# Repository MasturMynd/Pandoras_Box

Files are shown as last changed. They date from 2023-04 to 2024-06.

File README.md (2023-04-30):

# Pandoras_Box

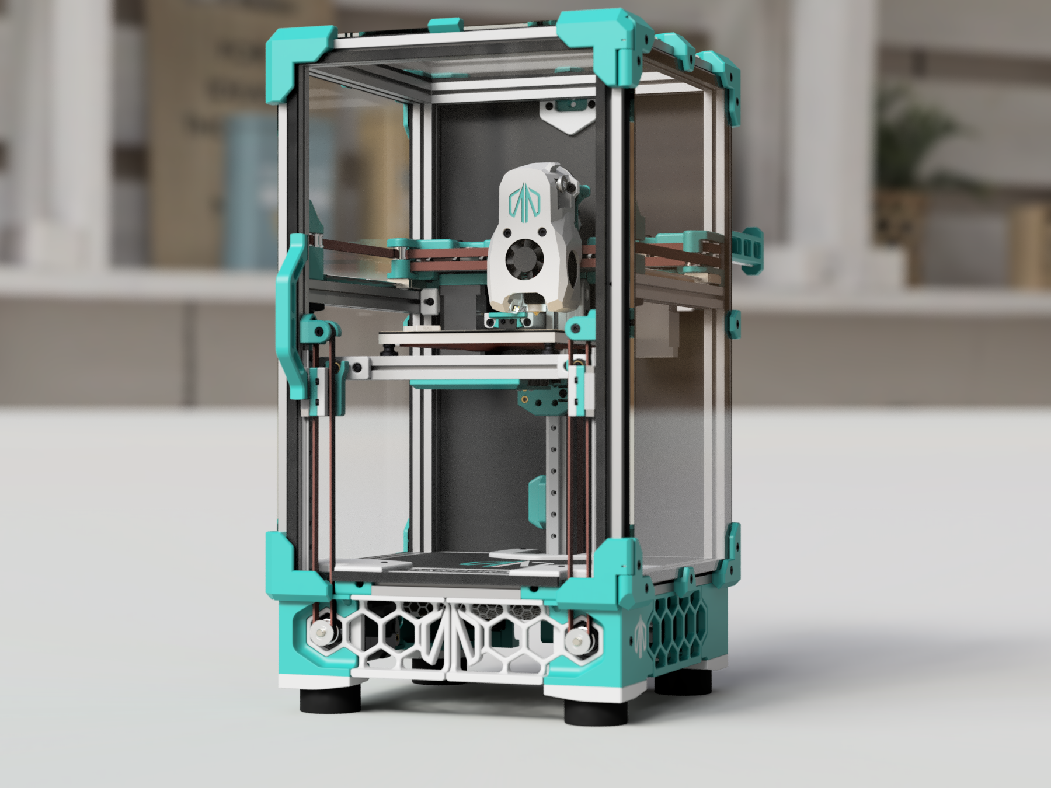
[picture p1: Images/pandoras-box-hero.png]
Pandoras_box_full


Pandora's Box is a modified version of the popular Voron V0 3D printer design. The printer has been enhanced with additional X and Y travel, a triple belted Z kinematic system, and an automatic bed tramming and meshing system.

## Features

- Increased X and Y travel - More room for activities!
- Triple belted Z kinematic system for stability and precision during Z-axis movement
- Automatic bed tramming and meshing system for effortless leveling of the print bed
- High-quality prints with improved accuracy and consistency
- Sturdy construction and triple belted Z kinematic system prevent any wobbling or shaking during printing

BOM
---
| Category | Part Description | Qty | Notes |
| --- | --- | --- | --- |
| Filament | Estimates based on the initial release | | |
| | Primary Color | 600g | |
| | Accent Color | 200g | |
| Fasteners | Listed quantities are minimum, buy extra! | | |
| | M2x6 FHCS | 9 | |
| | M2x6 SHCS | 62 | |
| | M2 Nut | 50 | |
| | M2x10 Self Tapping Screws for Plastic | 9 | |
| | M3x6 BHCS | 46 | |
| | M3x8 BHCS | 48 | |
| | M3x10 BHCS | 16 | |
| | M3x12 BHCS | 15 | |
| | M3x16 BHCS | 13 | |
| | M3x25 BHCS | 5 | |
| | M3x30 BHCS | 10 | |
| | M3x35 BHCS | 4 | |
| | M3x40 BHCS | 4 | |
| | M3x8 SHCS | 36 | |
| | M3x10 SHCS | 51 | |
| | M3x12 SHCS | 5 | |
| | M3x14 SHCS | 3 | Used only with Formbot build plates |
| | M3x16 SHCS | 7 | |
| | M3x20 SHCS | 4 | |
| | M3x25 SHCS | 6 | |
| | M3x30 SHCS | 4 | |
| | M3x35 SHCS | 2 | |
| | 3x6x0.5 Shim Washer | 42 | |
| | M3 Nut | 148 | |
| | M3 Brass heatstake inserts - short M3x5x4 | 62 | |
| | M5x16 BHCS | 4 | |
| | M5 Nut | 4 | |
| Frame | | | Full frame kit available at [DLLPDF](https://dllpdf.com/pandoras-box-frame)! |
| | Makerbeam XL 15x15 350mm | 4 | |
| | Makerbeam XL 15x15 200mm | 13 | |
| | Makerbeam XL 15x15 100mm | 3 | |
| Electronics | | |
| | Raspberry Pi Compute Module 4 | 1 | Alternative: Bigtreetech CB1 |
| | Omron Mouse Button - Micro Switch | 2 | |
| | NEMA17 Stepper Motor 45Ncm | 3 | Z Steppers - NEMA14 mounting also available |
| | NEMA14 Stepper Motor 40Ncm | 2 | |
| | MicroSD Card | 1 | |
| | Meanwell LRS-150-24 | 1 | UHP-200-24 is a stronger alternative |
| | IEC320 C14 inlet | 1 | |
| | Hotend thermistor | 1 | |
| | Hotend | 1 | |
| | C13 Power Cord | 1 | |
| | Bigtreetech Manta M8P | 1 | Alternative: Bigtreetech Manta M5P + CAN Toolhead Board |
| | 3M 5952 VHB tape | 1 | |
| | 3010 Blower Fan | 2 | |
| | 3010 Axial fan | 1 | |
| | 4010 Axial fan | 2 | |
| | 24V Heater Cartridge | 1 | |
| Cables | | |
| | Wire 18gauge 10ft | 1 | |
| | Thermal Fuse 125C | 1 | |
| | Nylon Cable Ties (1.8mm wide or smaller) | 50 | |
| | Microfit3 Dual Row (10circuits) Male & Female Plug | 1 | |
| | JST connectors (2pin 3pin 4pin) | ? | |
| | Insulated Crimp Receptical | 4 | |
| | High Flex Wire 22gauge 100ft | 1 | |
| | High Flex Wire 20gauge 10ft | 1 | |
| | 7mm x 7mm cable chain (less than 1/2 meter needed) | 1 | |
| | WAGO 221-412 (OPTIONAL) | 7 | |
| Motion | | |
| | MGN7H Linear Rail with Carriage - 150mm | 5 | |
| | MGN9H Linear Rail with Carriage - 200mm | 1 | |
| | GT2 Open Belt (6mm W) - 4000mm | 1 | |
| | GT2 20T (5mm ID 6mm W) | 5 | |
| | GT2 20T (5mm ID 6mm W) Deflanged | 1 | |
| | F623-RS Bearing | 42 | |
| | KGLM-03 Spherical Bearing	 | 3 | |
| | 5x25mm Shaft (Length varies by setup) | 1 | |
| Buildplate | | |
| | M4 Knurled Nut | 3 | |
| | Spring Steel Flex Buildplate 120x120mm (OPTIONAL) | 1 | |
| | Silicone DC 24V Heater 100x100mm 60W | 1 | |
| | PEI + 3M 468MP (200MP) | 1 | |
| | MIC6 1/4" Plate - 120x120mm | 1 | |
| Panels | | | Full panels kit available at [DLLPDF](https://dllpdf.com/pandoras-box-panels)! |
| | Rear Panel 3mm thick (See DXF) | 1 | |
| | Deck Panel 3mm thick (See DXF) | 1 | |
| | Acrylic Sheet Clear - 212x332x3mm | 3 | |
| | Acrylic Sheet Clear - 212x212x3mm | 1 | |
| | Single Sided Foam Tape 3mm Thick (5m) | 1 | |
| Bowden | | |
| | Bowden Tube 4x2mm - 1m | 1 | |
| | Bowden Fitting | 2 | |
| Misc. | | |
| | Rubber Foot (1.5x.75", 38x19mm) | 4 | |
| | Bowden Tube 4x3mm - 1m | 1 | |
| | 6mm x 3mm Round Neodymium Magnets | 18 | |
| Extruder | | |
| | NEMA14 36mm pancake Motor with 10 tooth gear | 1 | |
| | MR85 Bearing | 2 | |
| | Bondtech BMG Extruder Kit | 1 | |

## Usage

The Pandora's Box design can be used by hobbyists and professionals alike to produce high-quality 3D prints. The automatic bed tramming and meshing system saves time and effort while ensuring consistent and level prints.

## Contributing

If you would like to contribute to the Pandora's Box design or submit mods specific to this design, please feel free to fork the repository and submit a pull request with your changes. I welcome any and all contributions that help to improve the design and make it even more useful for the 3D printing community.

## License

The Pandora's Box 3D printer design is licensed under the GPLv3 License. Please see the `LICENSE` file for more information.

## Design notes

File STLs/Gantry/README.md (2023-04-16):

# Mini Stealthburner - MasturMods Edition

Mini Stealthburner - MasturMods Edition

There are two parts needed for this front cowling. First, print the insert out of your primary color. After you have that part ready slice the main body and insert a filament change or pause command at layer 16 (assuming traditional Voron print standards). When the print for the main body pauses, drop the insert into the formed gap in the part. This allows for a recessed logo with some flare!

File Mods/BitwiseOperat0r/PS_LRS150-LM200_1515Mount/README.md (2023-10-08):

Power supply mount for Meanwell LRS-150 or Mornsun LM200.

This is for standard Pandora's Box(NOT the +50)

I might want to go back and add some cable management to the mounts




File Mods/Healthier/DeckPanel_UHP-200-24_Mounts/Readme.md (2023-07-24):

# Deck Panel with UHP-200-24 mounts (Mastur_Mynd logo)

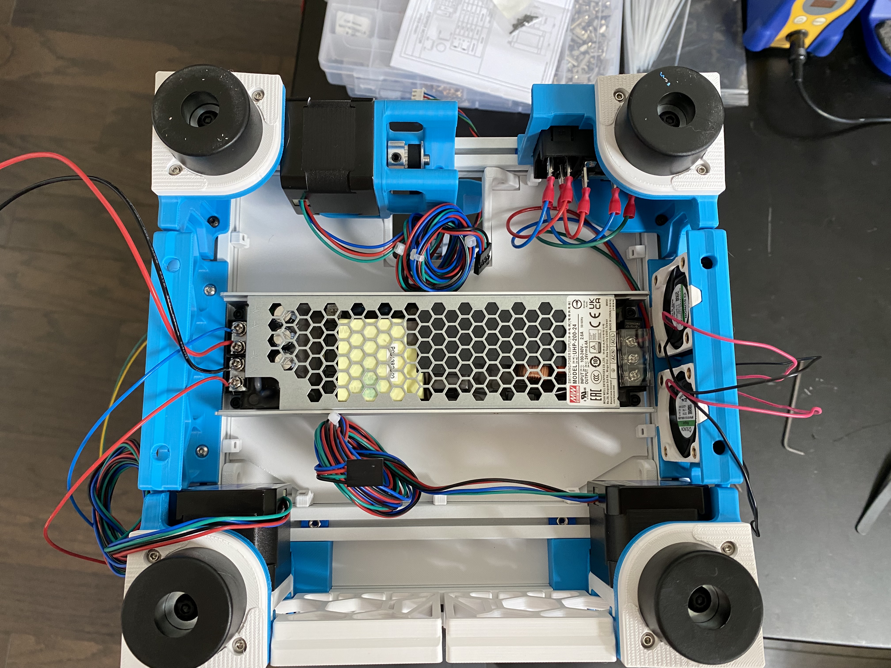
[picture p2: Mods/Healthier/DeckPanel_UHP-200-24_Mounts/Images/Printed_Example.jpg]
Printed_Example


A modified version of the Pandora Deck panel with raised spots for 3x4x5 heatset inserts in a pattern fitting a UHP-200-24

# Photos

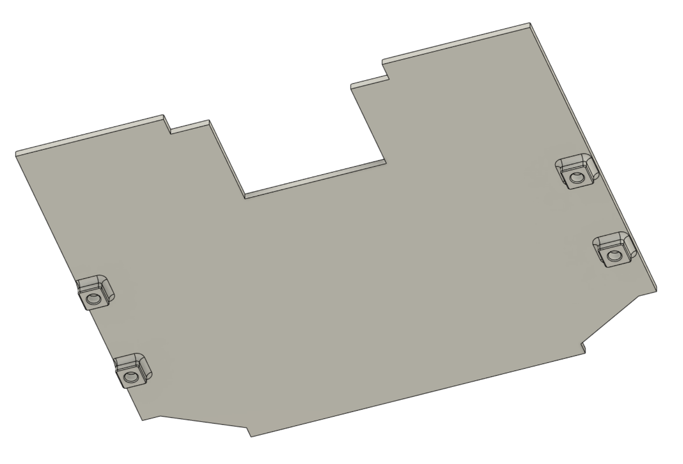
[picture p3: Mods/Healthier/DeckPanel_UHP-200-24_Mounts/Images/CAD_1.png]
CAD_1

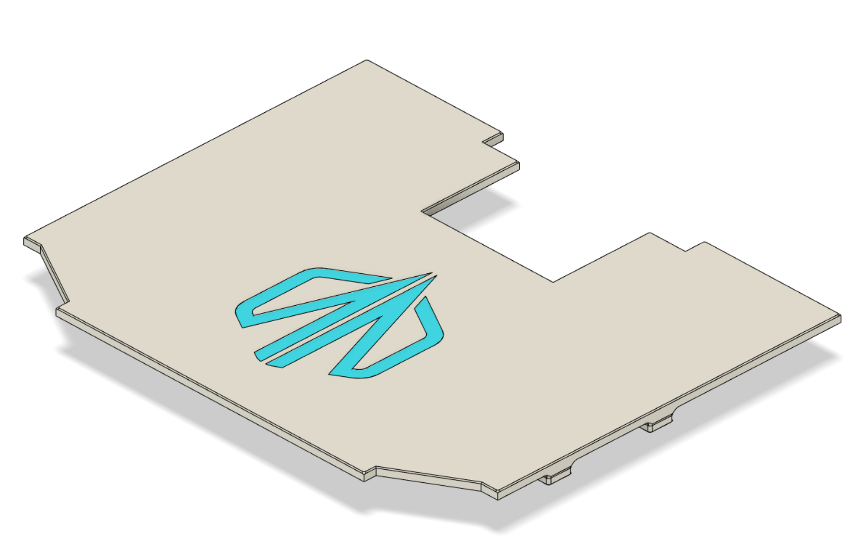
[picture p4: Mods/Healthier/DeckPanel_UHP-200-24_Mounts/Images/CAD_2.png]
CAD_2


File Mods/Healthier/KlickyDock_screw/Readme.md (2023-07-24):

# Klicky probe dock for Pandora - Screw option and better mounting support

A modified version of the Pandora Klicky probe mount / arm that supports a Black Oxide M3x8 SHCS screw in addition to the normal magnet.  This allows for variable strength of the magnet holding the probe in the dock.  In addition, the stabilizers around the mounting holes of the arms have been extended to the sides of the arm for better mounting stability.

# Photos

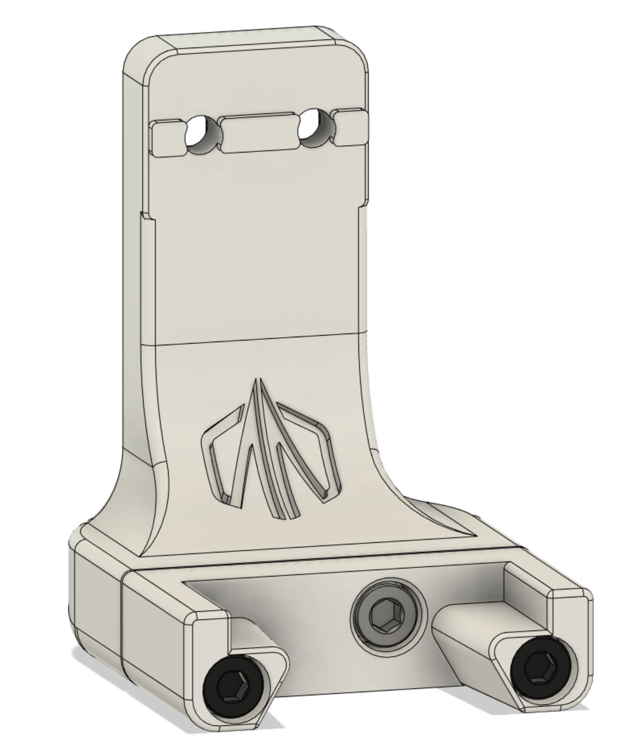
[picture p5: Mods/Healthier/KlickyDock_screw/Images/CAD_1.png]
CAD_1


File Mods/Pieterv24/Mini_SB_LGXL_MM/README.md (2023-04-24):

# Mini Stealthburner LGXL (Mastur_Mynd logo)

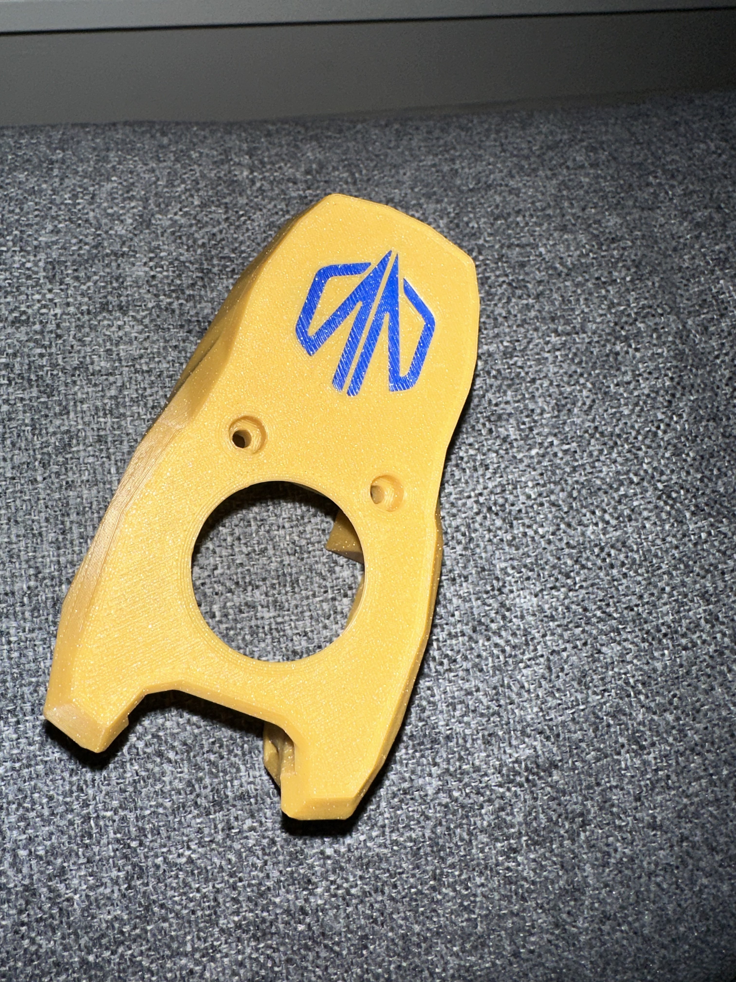
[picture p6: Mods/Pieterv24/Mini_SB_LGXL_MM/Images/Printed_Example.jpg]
Printed_Example


A modified version of the Mini Stealthburner LGLX cowling, with the Mastur_Mynd logo

[Original cowling](https://github.com/PrintersForAnts/Crucible/tree/main/MiniSB_LGXL)

# Photos

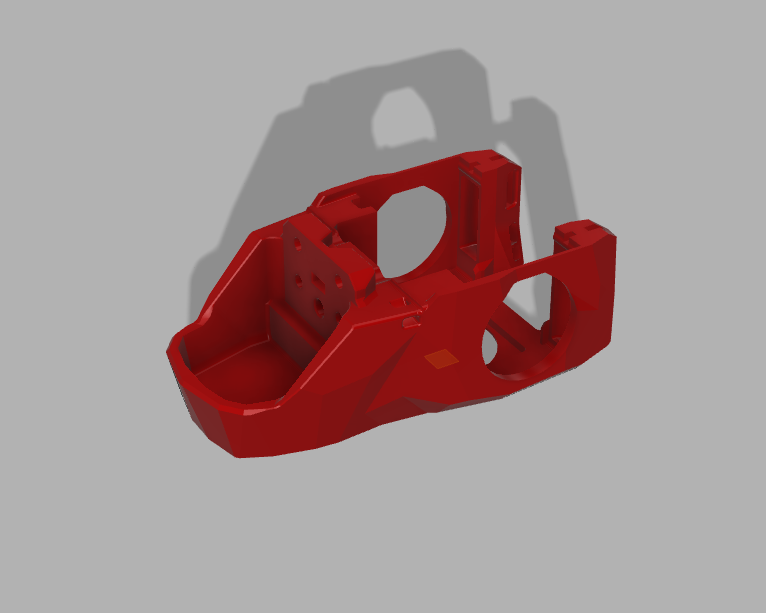
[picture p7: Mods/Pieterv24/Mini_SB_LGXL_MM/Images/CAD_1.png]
CAD_1

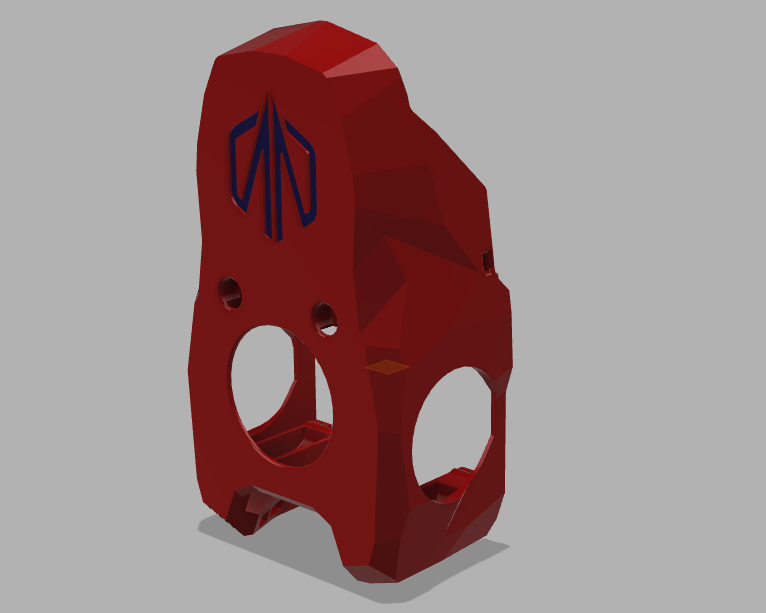
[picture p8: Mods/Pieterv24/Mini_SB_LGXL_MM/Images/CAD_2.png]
CAD_2

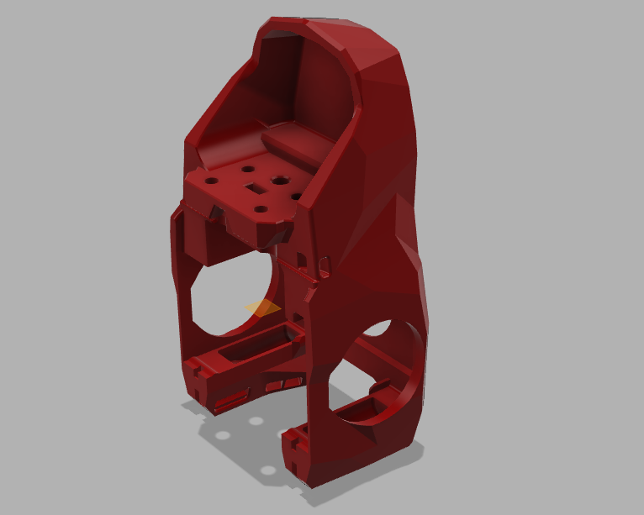
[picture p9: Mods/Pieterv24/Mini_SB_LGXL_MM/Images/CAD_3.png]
CAD_3


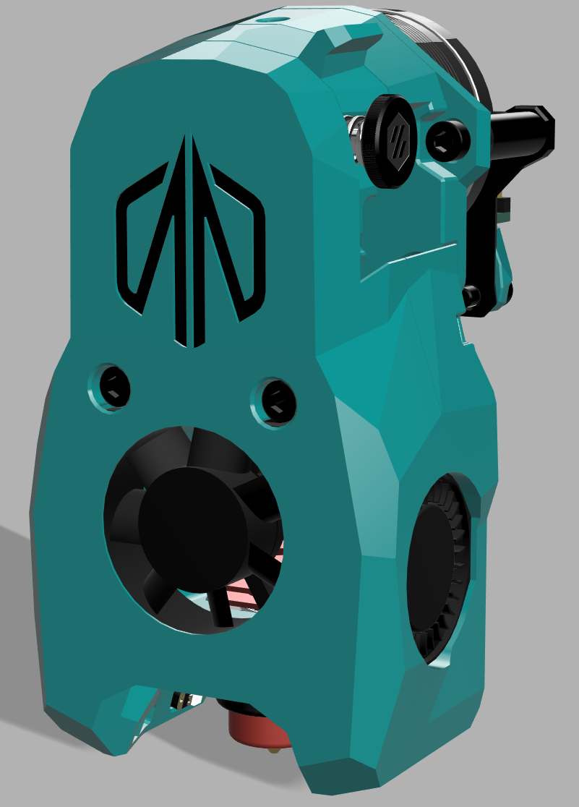
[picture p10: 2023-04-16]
Images/minisb_mm.png

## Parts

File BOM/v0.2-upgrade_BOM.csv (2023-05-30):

Category | Part Description | QTY | Notes
--- | --- | --- | ---
Filament | Estimates based on the initial release
 | Primary Color | 600g
 | Accent Color | 200g
Fasteners |  |  | Listed quantities are minimum. Buy extra!
 | M2x6 SHCS | 2
 | M2x10 Self Tapping Screws for Plastic | 9
 | M3x6 BHCS | 6
 | M3x16 BHCS | 3
 | M3x8 SHCS | 36
 | M3x10 SHCS | 51
 | M3x12 SHCS | 5
 | M3x14 SHCS | 3 | Only for Formbot build plates
 | M3x16 SHCS | 7
 | M3x20 SHCS | 4
 | M3x25 SHCS | 6
 | M3x30 SHCS | 4
 | M3x35 SHCS | 2
 | M3 Nut | 8
 | M3 Brass heatstake inserts | 12 | short M3x5x4
 | M5x16 BHCS | 4
 | M5 Nut | 4
Frame
 | Makerbeam XL 15x15 350mm | 4
Electronics
 | Raspberry Pi Compute Module 4 | 1
 | Omron Mouse Button - Micro Switch | 1
 | NEMA17 Stepper Motor 45Ncm | 3
 | Bigtreetech Manta M8P | 1
 | 4010 Axial fan | 2
Cables
 | WAGO 221-412 (OPTIONAL) | 7
Motion
 | MGN9H Linear Rail with Carriage - 200mm | 1
 | GT2 Open Belt (6mm W) - 4000mm | 1
 | GT2 20T (5mm ID 6mm W) | 3
 | GT2 20T (5mm ID 6mm W) Deflanged | 1
 | F623-RS Bearing | 18
 | KGLM-03 Spherical Bearing | 3
 | 5x25mm Shaft (Length varies by setup) | 1
Buildplate
 | M4 Knurled Nut | 3
Panels
 | Rear Panel 3mm thick (See DXF) | 1
 | Deck Panel 3mm thick (See DXF) | 1
 | Acrylic Sheet Clear - 212x332x3mm | 3
 | Acrylic Sheet Clear - 212x212x3mm | 1
 | Single Sided Foam Tape 3mm Thick (5m) | 1
Misc.
 | Rubber Foot (1.5x.75in - 38x19mm) | 4
 | 6mm x 3mm Round Neodymium Magnets | 10

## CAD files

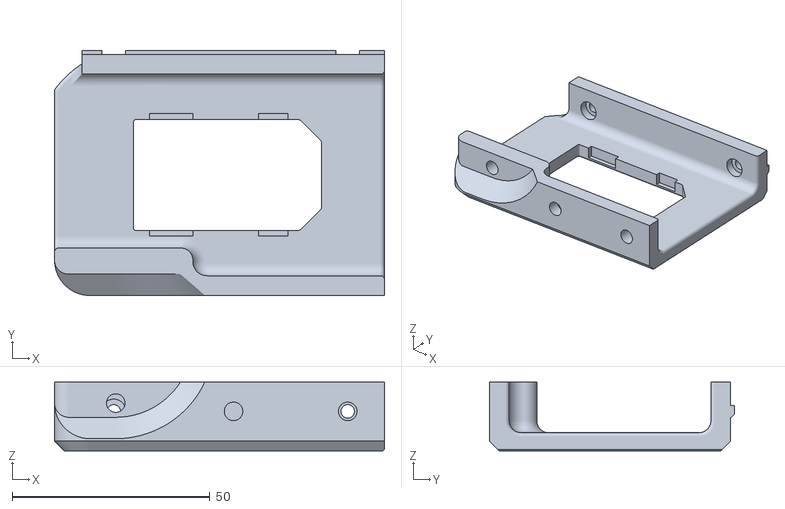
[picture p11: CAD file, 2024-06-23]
Mods/Mastur_Mynd/G2Z/STLs/Skirts/[a]_mains_inlet v17.stl
83.5 x 62.0 x 17.4

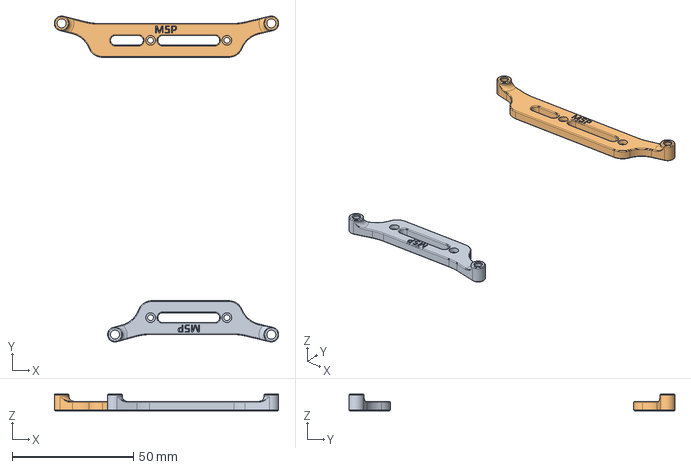
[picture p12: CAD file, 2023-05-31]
CAD/btt_manta_m5p_brackets.step
92.6 x 134.5 x 7.00 mm

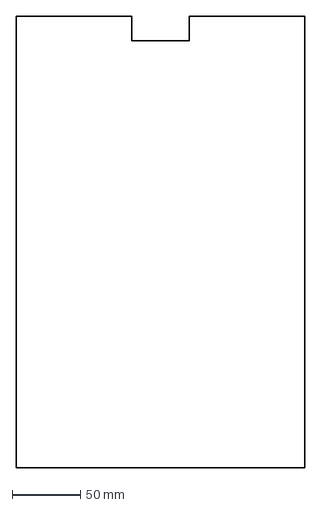
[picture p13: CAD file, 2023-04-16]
DXF/panel_rear.dxf
212.0 x 332.0 mm

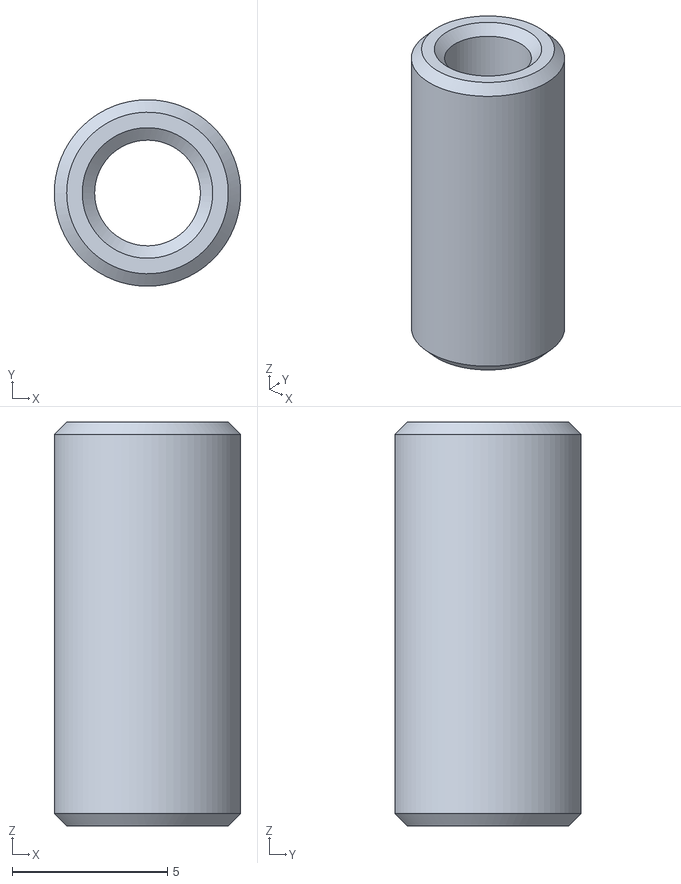
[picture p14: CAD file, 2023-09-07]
Mods/actualbigbobin/Pandora Nema17/STL/10mm/[a]_6x12mm_spacer_x2.stl
6.00 x 6.00 x 13.0

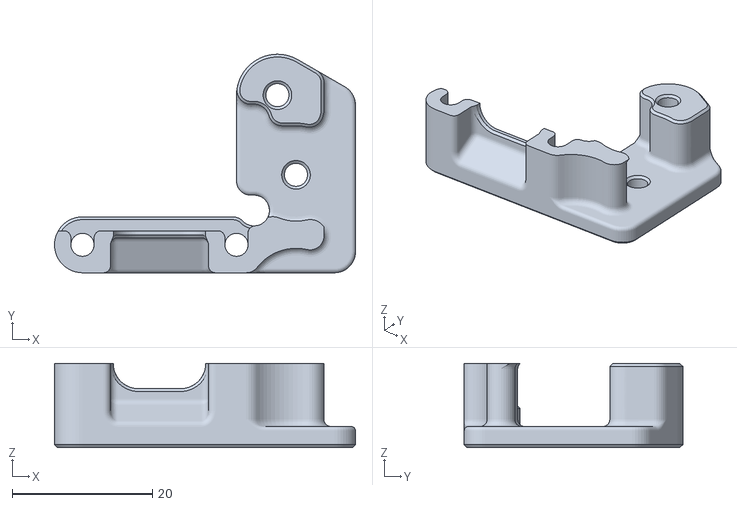
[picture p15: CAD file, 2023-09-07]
Mods/actualbigbobin/Pandora Nema17/STL/6mm/XY Joint Right Upper.stl
43.0 x 31.2 x 12.0

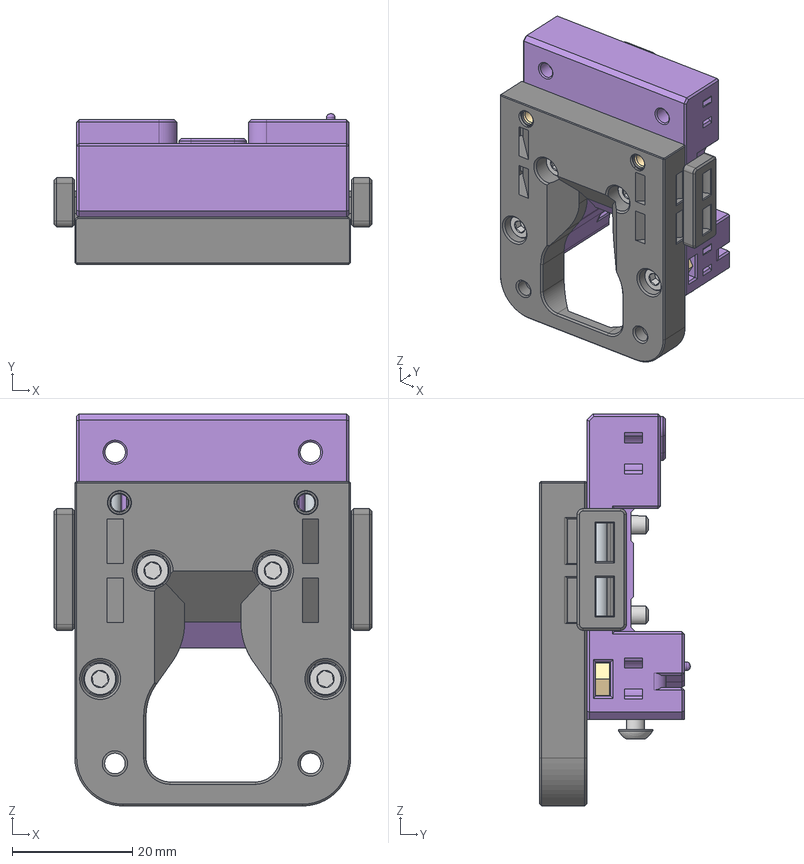
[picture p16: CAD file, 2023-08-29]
Mods/actualbigbobin/Xol Carriage/CAD/Xol_Carriage_MGN9H PB.step
52.7 x 25.0 x 65.1 mm
Xol_Carriage_Rear_MGN9H (1)
Xol_Carriage_Front_MGN9H (1)
M3x8 SHCS (2) x 8
M3 Threaded Insert (1) v1 (2) x 7
M3x6 BHCS (2) x 2
M3 Hexnut (2) x 2
M2 Threaded Insert (1)
Parallel Pin 3 x 26 (1) x 2
Parallel Pin 3 x 26 (1) (1) x 2

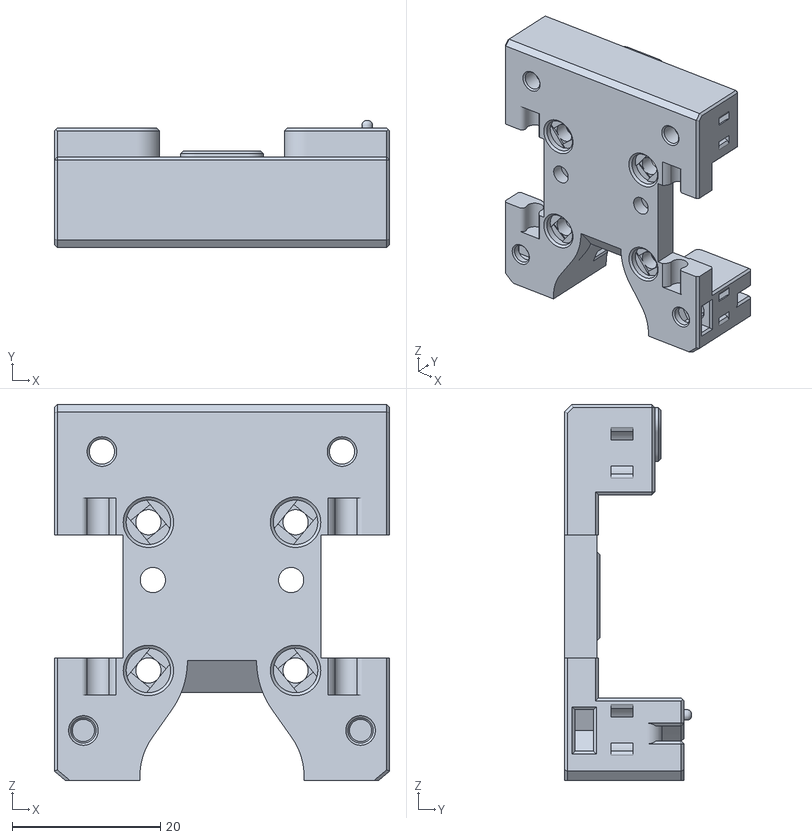
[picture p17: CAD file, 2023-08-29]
Mods/actualbigbobin/Xol Carriage/STL/MGN12H/back.stl
45.3 x 17.2 x 50.7

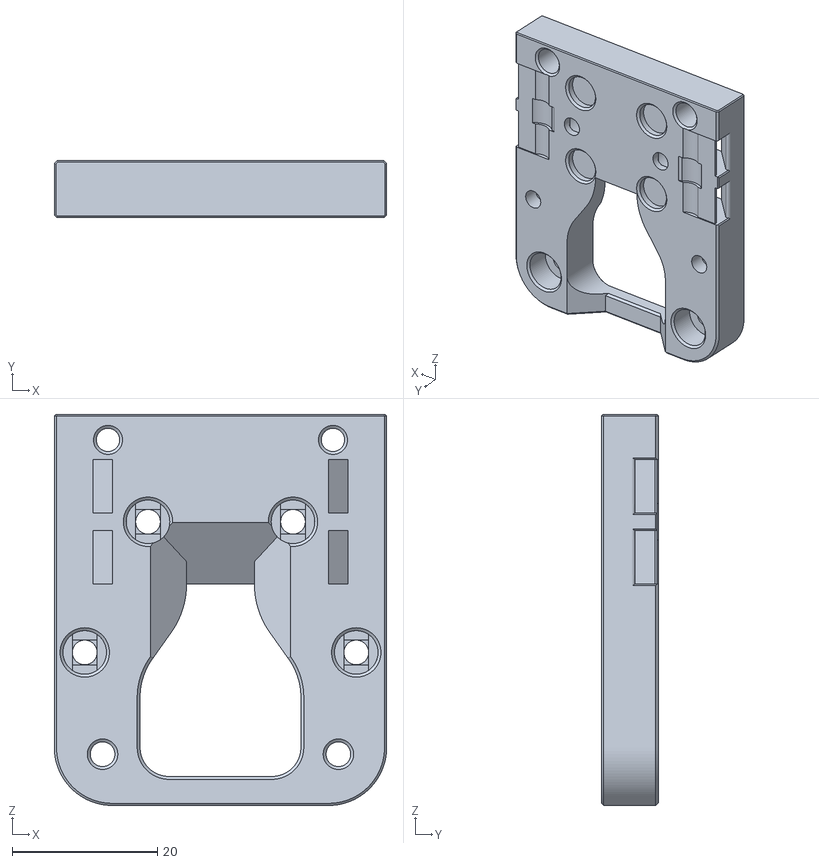
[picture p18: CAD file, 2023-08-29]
Mods/actualbigbobin/Xol Carriage/STL/MGN9H/front.stl
45.8 x 7.84 x 53.9

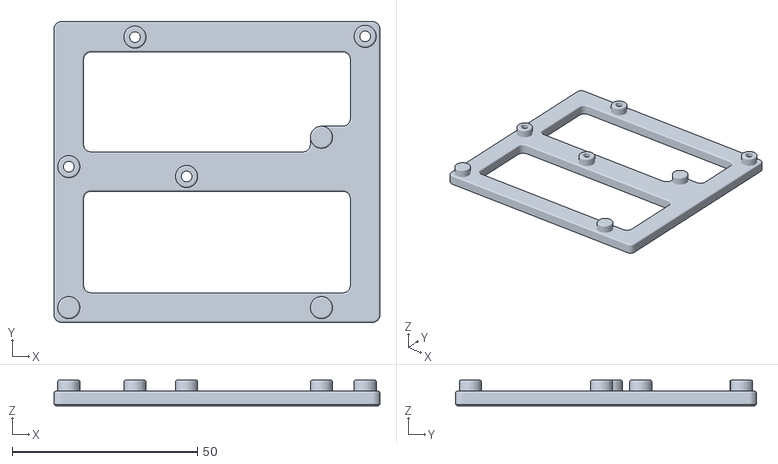
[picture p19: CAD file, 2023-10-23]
Mods/BitwiseOperat0r/Manta-E3EZ_Mount/STLs/Manta-E3EZ_Mount.stl
88.0 x 81.2 x 7.00

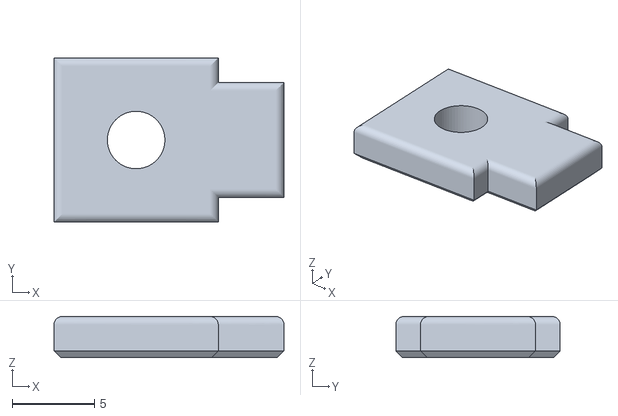
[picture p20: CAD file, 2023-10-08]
Mods/BitwiseOperat0r/PS_LRS150-LM200_1515Mount/STLs/PSMountClamp_x4.stl
14.0 x 10.0 x 2.50

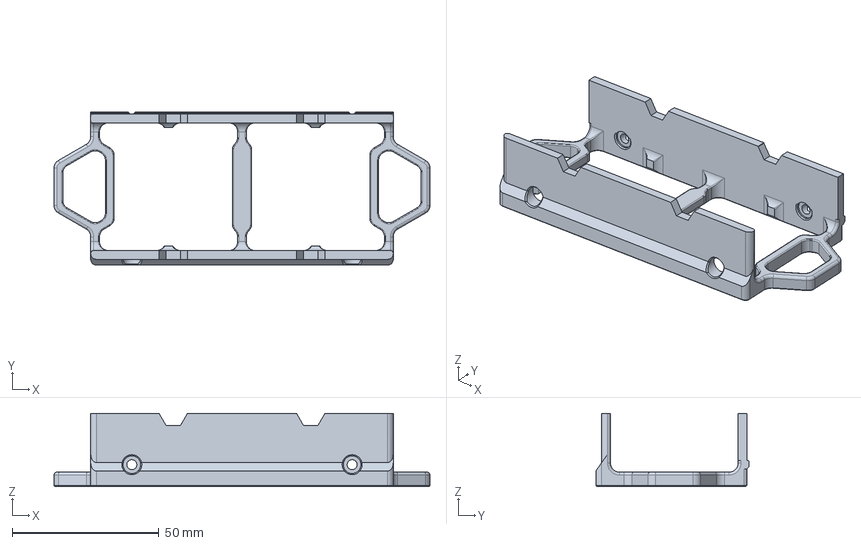
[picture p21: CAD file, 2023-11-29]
Mods/camelCaseOnly/Side Skirt - 4020 Fan.step
128.0 x 52.2 x 25.0 mm

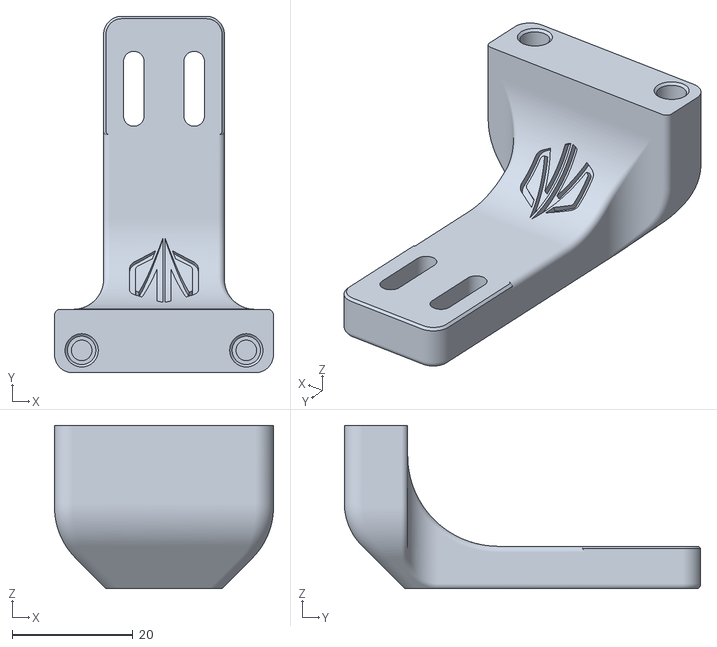
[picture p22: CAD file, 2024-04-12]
Mods/Caza/Adjustable_Klicky_Dock/Pandora_Adjustable_Klicky_Dock_001.stl
36.3 x 59.0 x 27.0

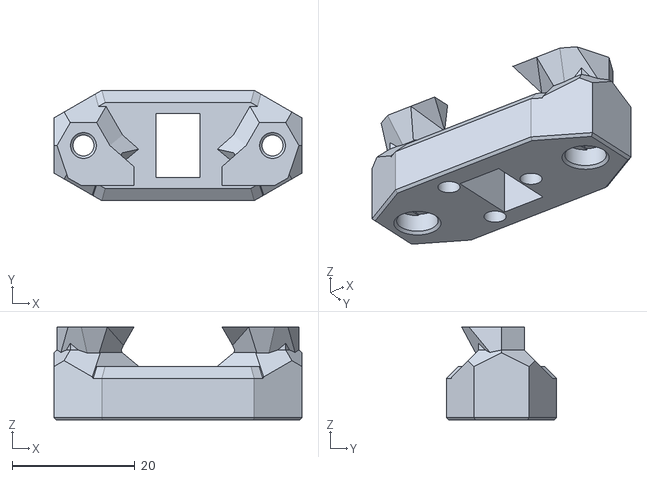
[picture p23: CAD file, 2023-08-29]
Mods/Caza/Kicky PCB/Klicky_PCBv1.stl
40.4 x 18.0 x 15.1

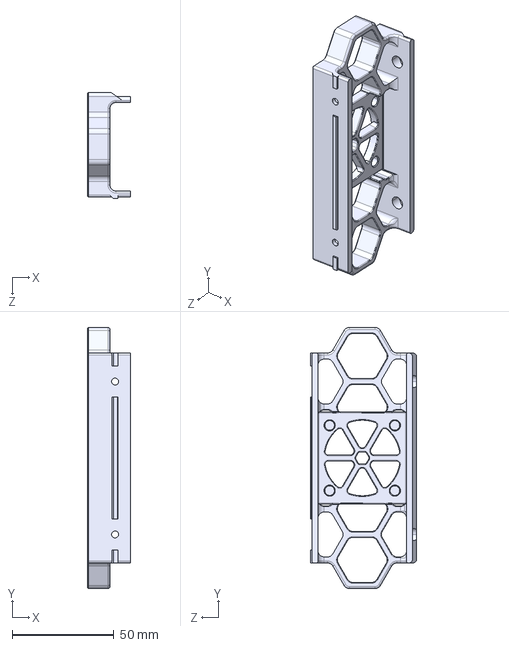
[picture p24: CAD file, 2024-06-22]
Mods/drataiczak/Side_Skirts_4010_Single/Bottom_Side_Skirt_Fan.STEP
21.0 x 128.0 x 52.2 mm

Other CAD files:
Mods/Healthier/DeckPanel_UHP-200-24_Mounts/CAD/Deck Panel_UHP-200-24_Mounts.step
Mods/Mastur_Mynd/Extrusionless_MGN12/xy_joint_right_upper.stl
Mods/Mastur_Mynd/G2Z/STLs/Drives/[a]_g2_motor_plate_right.stl
Mods/Mastur_Mynd/G2Z/STLs/Skirts/[a]_corner_baseplate_a_x2.stl
CAD/name_plate.f3d
DXF/panel_deck.dxf
DXF/panel_front_and_sides.dxf
DXF/panel_name_blank.dxf
DXF/panel_top.dxf
Mods/BitwiseOperat0r/Manta-E3EZ_Mount/CAD/Manta-E3EZ_Mount.f3d
Mods/BitwiseOperat0r/PS_LRS150-LM200_1515Mount/CAD/PS_LRS150-LM200_1515Mount.f3d
Mods/BitwiseOperat0r/PS_LRS150-LM200_1515Mount/STLs/PSMount_x2.stl
Mods/Healthier/DeckPanel_UHP-200-24_Mounts/STLs/Deck Panel_UHP-200-24_Mounts.stl
Mods/Healthier/KlickyDock_screw/CAD/KlickyDockScrew.step
Mods/Healthier/KlickyDock_screw/STLs/[a]_klicky_probe_dock.stl
Mods/Healthier/KlickyDock_screw/STLs/[a]_klicky_probe_dock_arm.stl
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

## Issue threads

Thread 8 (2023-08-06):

Poor probe accuracy at max Y

MasturMynd, 2023-08-06:
Due to the asymmetric belt mounting / tensioning between the front and rear z set, probing near the rear of the bed is known to be inconsistent without significant attention to detail.

NeighNeighNeigh, 2023-11-24:
I'm very close to committing to building a Pandora's Box (instead of my stock V0.2 kit) – but hoping you might elaborate on the implications of this issue? Should I be concerned?

MasturMynd, 2023-11-29:
> I'm very close to committing to building a Pandora's Box (instead of my stock V0.2 kit) – but hoping you might elaborate on the implications of this issue? Should I be concerned?

This issue has been addressed via a mod that has been tested with a number of builds from the DoomCube discord server. I'll be publishing said mod shortly!

Closed 2023-11-29.

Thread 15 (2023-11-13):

Manual's page 93 is flipped

HitLuca, 2023-11-13:
Looks like the page 93 of the assembly manual is flipped horizontally

LillianaMirrors, 2023-11-13:
Known issue, will be fixed in the next revision, coming soonTM

MasturMynd, 2023-11-29:
Reopening as this doesn't appear to have been resolved yet.

Closed 2024-02-02.

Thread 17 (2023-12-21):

Pg 55 has extrusion labeled G, should be F

ReillyBex, 2023-12-21:
Shows “G” extrusion being affixed to gantry brace on page 55 of the current manual. Pretty sure it should be “F”, but I might just be tripping.

MasturMynd, 2024-02-02:
The "G Extrusion" wouldn't need tapped ends. It doesn't look like there's a callout for this and I, sadly, don't have files to edit this manual =/

Closed 2024-09-23.

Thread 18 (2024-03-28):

Is documentation complete?

Otann, 2024-03-28:
I was wondering, whether the documentation in PDF is completed or is it still in progress?

I could not find the A and E extrusions specs. My understanding that E extrusion is same as in the standard V0?

And is the page 127 the last one?

tiditidi, 2024-03-30:
Nah the document kinda stops there, and I believe the extrusions were a bit incomplete as well. I remember having to look at the cad to make certain a few times

I don't remember if they match, but looking at the cad is the best way to tell for sure. Might as well get comfy with the cad since that is the only way to finish out the build atm

Not sure if there is more work happening on the pdf

MasturMynd, 2024-04-08:
I really need to dig into the manual. A friend was working on it for me but got busy with school and life so they haven't been able to get anything further done. I'll likely end up having to do a rewrite since I don't have their source files and that probably won't be able to happen until either after RMRRF or MRRF.

Drmcshorty, 2024-09-23:
Are there any updates on the manual being continued?

Closed 2024-09-23.

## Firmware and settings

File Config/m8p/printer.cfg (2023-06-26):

[include mainsail.cfg]
[include sensorless.cfg]

[mcu]
serial: # Define your MCU serial
#restart_method: command
##--------------------------------------------------------------------

[printer]
kinematics: corexy
max_velocity: 300  
max_accel: 3000
max_z_velocity: 100
max_z_accel: 3000
square_corner_velocity: 5.0

[temperature_sensor M8P]
sensor_type: temperature_mcu

[temperature_sensor CM4]
sensor_type: temperature_host

#####################################################################
#	X/Y Steppers - M1 and M2
#
#		Multiply the peak current by 0.707 to determine the maximum
#		current in RMS. This is the maximum run current. (Typically
#		round down to the nearest .1)
#####################################################################

# M1
[stepper_x]
step_pin: PE2
dir_pin: PB4
enable_pin: !PC11
microsteps: 32
rotation_distance: 40
endstop_pin: tmc2209_stepper_x:virtual_endstop
position_min: -12
position_endstop: 132
position_max: 132
homing_speed: 50
homing_retract_dist: 0
homing_positive_dir: true

[tmc2209 stepper_x]
uart_pin: PC10
interpolate: True
run_current: 0.9
sense_resistor: 0.110
stealthchop_threshold: 0
diag_pin: ^PF3
driver_SGTHRS: 255 	<-!-!-!- Tune sensorless homing

# M2
[stepper_y]
step_pin: PF12
dir_pin: PF11
enable_pin: !PB3
microsteps: 32
rotation_distance: 40
endstop_pin: tmc2209_stepper_y:virtual_endstop
position_min: -2
position_endstop: 125
position_max: 125
homing_speed: 50
homing_retract_dist: 0
homing_positive_dir: true

[tmc2209 stepper_y]
uart_pin: PF13
interpolate: True
run_current: 0.9
sense_resistor: 0.110
stealthchop_threshold: 0
diag_pin: ^PF4
driver_SGTHRS: 255 	<-!-!-!- Tune sensorless homing

#####################################################################
#	Z Steppers - M3, M4 and M5
#
#		Multiply the peak current by 0.707 to determine the maximum
#		current in RMS. This is the maximum run current. (Typically
#		round down to the nearest .1)
#####################################################################

## Front Left - M3
[stepper_z]
step_pin: PD7
dir_pin: !PD6
enable_pin: !PF10
rotation_distance: 40
microsteps: 32
endstop_pin: # PF5 / probe:z_virtual_endstop 	<-!-!-!- Define your Z endstop pen or use the probe for boop
position_max: 120
position_min: -4
homing_speed: 8
second_homing_speed: 8
homing_retract_dist: 3

[tmc2209 stepper_z]
uart_pin: PF9
interpolate: true
run_current: 1.0
sense_resistor: 0.110
stealthchop_threshold: 999999

##  Rear Center - M4
[stepper_z1]
step_pin: PD3
dir_pin: PD2
enable_pin: !PD5
rotation_distance: 40
microsteps: 32

[tmc2209 stepper_z1]
uart_pin: PD4
interpolate: true
run_current: 1.0
sense_resistor: 0.110
stealthchop_threshold: 999999

##  Front Right - M5
[stepper_z2]
step_pin: PC9
dir_pin: PC8
enable_pin: !PD1
rotation_distance: 40
microsteps: 32

[tmc2209 stepper_z2]
uart_pin: PD0
interpolate: true
run_current: 1.0
sense_resistor: 0.110
stealthchop_threshold: 999999

#####################################################################
#	Extruder - M7
#
#		Multiply the peak current by 0.707 to determine the maximum
#		current in RMS. This is the maximum run current. (Typically
#		round down to the nearest .1)
#####################################################################

[extruder]
step_pin: PD12
dir_pin: !PD11
enable_pin: !PD14
rotation_distance: 22.650 		<-!-!-!- Calibrate rotation distance
gear_ratio: 50:10
microsteps: 32
full_steps_per_rotation: 200
filament_diameter: 1.75
heater_pin: PB6
sensor_pin: PA1
#sensor_type: 				<-!-!-!- Define your temperature sensor
max_extrude_only_distance: 100.0
max_temp: 295
min_extrude_temp: 150
min_temp: 0
nozzle_diameter: 0.400
control: pid				<-!-!-!- Run a PID tune
pid_kp: 22.331
pid_ki: 2.481
pid_kd: 50.246
pressure_advance: 0			<-!-!-!- Tune pressure advance
pressure_advance_smooth_time: 0.020

[tmc2209 extruder]
uart_pin: PD13
interpolate: false
run_current: 0.3
sense_resistor: 0.110
stealthchop_threshold: 0

#####################################################################
# 	Bed Heater
#####################################################################

[heater_bed]
heater_pin: PE1
sensor_type: 
sensor_pin: PA0
min_temp: 0
max_temp: 120
control: pid				<-!-!-!- Run a PID tune
pid_kp: 53.713
pid_ki: 1.312
pid_kd: 549.883

#####################################################################
# 	Probe
#####################################################################

[probe]
pin: ^PF6
#x_offset: 0				<-!-!-!- Set to the position x of your probe relative to the nozzle
#y_offset: 0				<-!-!-!- Set to the position y of your probe relative to the nozzle
#z_offset: 0				<-!-!-!- Set to the position z of your probe relative to the nozzle
speed: 8
samples: 3
samples_result: median
sample_retract_dist: 5
samples_tolerance: 0.01
samples_tolerance_retries: 3
#					<-!-!-!- Uncomment below if you are using Boop
#activate_gcode:
#    {% set PROBE_TEMP = printer.configfile.settings.extruder.min_extrude_temp %}
#    {% set MAX_TEMP = PROBE_TEMP + 5 %}
#    {% set ACTUAL_TEMP = printer.extruder.temperature %}
#    {% set TARGET_TEMP = printer.extruder.target %}
#
#    {% if TARGET_TEMP > PROBE_TEMP %}
#        { action_respond_info('Extruder temperature target of %.1fC is too high, lowering to %.1fC' % (TARGET_TEMP, PROBE_TEMP)) }
#        M109 S{ PROBE_TEMP }
#    {% else %}
#        # Temperature target is already low enough, but nozzle may still be too hot.
#        {% if ACTUAL_TEMP > MAX_TEMP %}
#            { action_respond_info('Extruder temperature %.1fC is still too high, waiting until below %.1fC' % (ACTUAL_TEMP, MAX_TEMP)) }
#            TEMPERATURE_WAIT SENSOR=extruder MAXIMUM={ MAX_TEMP }
#        {% endif %}
#    {% endif %}

#####################################################################
# 	Fan Control
#####################################################################

[multi_pin electronics_cooling]
pins: PE4, PB8

[fan]
pin: PE0
kick_start_time: 0.5
off_below: 0.10

[heater_fan hotend_fan]
pin: PE6
max_power: 1.0
kick_start_time: 0.5
heater: extruder
heater_temp: 50.0

[heater_fan controller_fan]
pin: multi_pin:electronics_cooling
kick_start_time: 0.5
heater: heater_bed
heater_temp: 45.0
fan_speed: 0.5

#####################################################################
# 	Homing and Gantry Adjustment Routines
#####################################################################

[idle_timeout]
timeout: 1800

[bed_mesh]
speed: 200
horizontal_move_z: 3
mesh_min: 10,10
mesh_max: 110,110
probe_count: 3,3
relative_reference_index: 4
algorithm: lagrange

[homing_override]
axes: xyz
gcode:
	{% set home_all = 'X' not in params and 'Y' not in params and 'Z' not in params %}

	{% if home_all or 'X' in params %}
		_HOME_X
	{% endif %}
	
	{% if home_all or 'Y' in params %}
		_HOME_Y
	{% endif %}
	
	{% if home_all or 'Z' in params %}
		G90
		G0 X150 Y150 F15000	# <-!-!-!- Set to the position of your Z endstop
		G28 Z
		G1 Z10
	{% endif %}
	
[z_tilt]
z_positions:
    -22.6, -16.4
    60, 151.3
    142.6, -16.4
points:
    10, 10
    60, 110
    110, 10
speed: 200
horizontal_move_z: 5
retries: 4
retry_tolerance: 0.0075

#####################################################################
# 	Macros
#####################################################################

[gcode_macro PRINT_END]
gcode:
    # safe anti-stringing move coords
    {% set th = printer.toolhead %}
    {% set x_safe = th.position.x + 20 * (1 if th.axis_maximum.x - th.position.x > 20 else -1) %}
    {% set y_safe = th.position.y + 20 * (1 if th.axis_maximum.y - th.position.y > 20 else -1) %}
    {% set z_safe = [th.position.z + 2, th.axis_maximum.z]|min %}
    
    SAVE_GCODE_STATE NAME=STATE_PRINT_END
    M400																	# wait for buffer to clear
    G92 E0																	# zero the extruder
    G1 E-5.0 F1800															# retract filament
    TURN_OFF_HEATERS														# Turn off bed, extruder, and fan
    G90																		# absolute positioning
    G0 X{x_safe} Y{y_safe} Z{z_safe} F20000									# move nozzle to remove stringing
    G0 X{th.axis_maximum.x//2} Y{th.axis_maximum.y - 10} F3600				# park nozzle at rear
    M107																	# turn off fan
    RESTORE_GCODE_STATE NAME=STATE_PRINT_END
    BED_MESH_CLEAR															# Clear the bed mesh
    M84																		# Disable steppers
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

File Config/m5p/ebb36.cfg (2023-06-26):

[mcu ebb36]
canbus_uuid: # your canbus uuid

[adxl345]
cs_pin: ebb36:PB12
spi_software_sclk_pin: ebb36:PB10
spi_software_mosi_pin: ebb36:PB11
spi_software_miso_pin: ebb36:PB2
axes_map: x,y,z

[resonance_tester]
accel_chip: adxl345
probe_points: 
  	60, 60, 20

[temperature_sensor ebb36]
sensor_type: temperature_mcu
sensor_mcu: ebb36

#####################################################################
# 	Endstops
#
# endstop_pin: ebb36:PB7
# endstop_pin: ebb36:PB6
# endstop_pin: ebb36:PB5
#
#####################################################################

#####################################################################
# 	I2C
#
# ebb36:PB4
# ebb36:PB3
#
#####################################################################

#####################################################################
#	Extruder
#
#####################################################################

[extruder]
step_pin: ebb36:PD0
dir_pin: !ebb36:PD1
enable_pin: !ebb36:PD2
rotation_distance: 22.650 # Calibrate rotation distance
gear_ratio: 50:10
microsteps: 32
full_steps_per_rotation: 200
filament_diameter: 1.75
nozzle_diameter: 0.400
heater_pin: ebb36:PB13
sensor_type: PT1000
sensor_pin: ebb36:PA3
# delete sensor_type and sensor_pin above then uncomment below to use the MAX31865 chip for a PT1000 or PT100
#sensor_type: MAX31865 
#sensor_pin: ebb36:PA4
#spi_bus: spi1
#rtd_nominal_r: 100
#rtd_reference_r: 430
#rtd_num_of_wires: 2
max_temp: 290
min_extrude_temp: 150
min_temp: 0
control: pid # PID tune
pid_kp: 21.625
pid_ki: 1.975
pid_kd: 59.200
max_extrude_only_distance: 100.0
pressure_advance: 0 # calibrate pressure advance
pressure_advance_smooth_time: 0.040

[tmc2209 extruder]
uart_pin: ebb36:PA15
interpolate: false
run_current: 0.3 # set an appropriate current
sense_resistor: 0.110
stealthchop_threshold: 0

#####################################################################
#   Fan and Lighting Control
#
# pin: ebb36:PD3 #5V RGB Header
#
#####################################################################

[fan]
pin: ebb36:PA0
kick_start_time: 0.5
off_below: 0.10

[heater_fan hotend_fan]
pin: ebb36:PA1
max_power: 1.0
kick_start_time: 0.5
heater: extruder
heater_temp: 50.0

#####################################################################
# 	Probe
#####################################################################

[probe]
pin: ^ebb36:PB9
#pin: ^ebb36:PB8
x_offset: 0
y_offset: 0
#z_offset: 0
speed: 8
samples: 3
samples_result: median
sample_retract_dist: 5
samples_tolerance: 0.01
samples_tolerance_retries: 3
#					<-!-!-!- Uncomment below if you are using Boop
#activate_gcode:
#    {% set PROBE_TEMP = printer.configfile.settings.extruder.min_extrude_temp %}
#    {% set MAX_TEMP = PROBE_TEMP + 5 %}
#    {% set ACTUAL_TEMP = printer.extruder.temperature %}
#    {% set TARGET_TEMP = printer.extruder.target %}
#
#    {% if TARGET_TEMP > PROBE_TEMP %}
#        { action_respond_info('Extruder temperature target of %.1fC is too high, lowering to %.1fC' % (TARGET_TEMP, PROBE_TEMP)) }
#        M109 S{ PROBE_TEMP }
#    {% else %}
#        # Temperature target is already low enough, but nozzle may still be too hot.
#        {% if ACTUAL_TEMP > MAX_TEMP %}
#            { action_respond_info('Extruder temperature %.1fC is still too high, waiting until below %.1fC' % (ACTUAL_TEMP, MAX_TEMP)) }
#            TEMPERATURE_WAIT SENSOR=extruder MAXIMUM={ MAX_TEMP }
#        {% endif %}
#    {% endif %}

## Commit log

2022-11-04 Added Filament Estimates
2022-11-05 Alpha Release
    [MGN7_rail_guide_x2.STL, MGN9_rail_guide_x2.stl, [a]_9mm_spacer_x2.stl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]
2022-11-07 Providing a proper CAD
    Accidentally exported the design as an STL rather than STEP for the CAD. Thanks to @actualbigbobin on the Voron discord for bringing this to my attention.
2023-01-10 Corrected BOM
    The panels section was only listing a single clear sheet, sized 212x332x3mm, when it should be 3.
2023-03-17 Corrected BOM
    [BOM.csv]
2023-04-16 R2 Rekease
    [BOM.csv, [a]_6x9mm_spacer_x2.stl, [a]_9mm_spacer_x2.stl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]
2023-04-16 Added Assembly Manual (WIP))
2023-04-17 Corrected CAD
2023-04-21 Added MGN12 CAD
2023-04-21 Commit Mini_SB_LGXL to mods folder
    [MM_MiniSB_LGXL v3.step, Mini_SB_LGXL_MM_logo.3mf]
2023-04-23 Added M8P Default Config
    [printer.cfg, sensorless.cfg]
2023-04-24 Added m2 nut bars
    [m2_nut_bar_x5.stl]
2023-04-24 Corrected BOM in README
2023-04-30 Added alternative PSU
    [BOM.csv]
2023-05-10 Update [a]_klicky_probe_dock_arm.stl
    Initial release of R2 had the dock arm ~3mm too low. Reducing the height of the part should result in less than 1mm of clearance between the arm and the toolhead carrier.
    [[a]_klicky_probe_dock_arm.stl]
2023-05-17 Update frame_brace_gantry.stl
    Added missing hatch support for the unsupported counterbore.
    [frame_brace_gantry.stl]
2023-05-19 Added V0.2 Upgrade BOM
    Comprehensive list of extra hardware needed when upgrading from the V0.2
    [new-build_BOM.csv, v0.2-upgrade_BOM.csv]
2023-05-20 Re-Added BOM Notes
    M3x14 SHCS are only used with some Formbot build plates due to either smaller thickness or too large of a counter bore.
    [v0.2-upgrade_BOM.csv]
2023-05-30 Published BTT Manta M5P Brackets
    I couldn't find any brackets that I liked that met the GPL3 license so I made some =)
    [BTT Manta M5P Brackets.step, btt_manta_m5p_brackets.stl, btt_manta_m8p_bracket_a.stl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]
2023-05-30 Corrected CAD Name
    big letters and spaces... WOOPS
    [btt_manta_m5p_brackets.step]
2023-05-31 Corrected Hole Diameter
    The mounting holes for one of the brackets were too large. This has been corrected.
    [btt_manta_m5p_brackets.step, btt_manta_m5p_brackets.stl]
2023-06-02 Added boop beta 4 versions
    [MM_MiniSB_LGXL_Boop_Beta4.step, MiniSB_LGXL_MM_Boop_Beta_4_Rev1.3mf]
2023-06-15 Update printer.cfg
    Some of the pins between the B (M1) and A (M2) motor pins were incorrectly assigned. Thanks, @Hifihedgehog, for bringing this to my attention!
    [printer.cfg]
2023-06-15 Update printer.cfg
    Moved setup notes closer to each field so they could more easily be seen.
    [printer.cfg]
2023-06-26 Added M5P config using USB to CAN passthrough
    [ebb36.cfg, printer.cfg, sensorless.cfg]
2023-07-23 KlickyDockScrew and UHP Deck Panel mods
    Added 2 changes I made while building as mods
    [Deck Panel_UHP-200-24_Mounts.step, Deck Panel_UHP-200-24_Mounts.stl, KlickyDockScrew.step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]
2023-08-29 Add files via upload
    PCB Klicky Carriage Mount
    [Klicky_PCBv1.stl]
2023-08-30 Nema 17 10mm and 6mm Variants
    Nema 17 motor cages and accompanying parts with 10mm and 6mm variants
    [MGN12 Retainer Bracket x2.stl, XY Joint Left Lower.stl, XY Joint Left Upper.stl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]
2023-11-15 4020 fan side skirt mod
    [Side Skirt - 4020 Fan.step, Side Skirt - 4020 Fan.stl]
2023-11-29 Add improved rear z tensioner
    [[a]_belt_clamp.stl, [a]_z_tensioner_rear.stl, belt_retainer.stl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]
2024-04-08 Add files via upload
    Adjustable Klicky dock
    [Pandora_Adjustable_Klicky_Dock_001.stl]
2024-04-18 Add STEP, STL for single 4010 skirts
    [Bottom_Side_Skirt_Fan.STEP]
2024-06-23 Full release of G2Z
    Located in Mods/Mastur_Mynd/G2Z
    [[a]_corner_baseplate_a_x2.stl, [a]_corner_baseplate_b_x2.stl, [a]_fan_grill_x2.stl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]
2024-10-29 Add Aluminium MGN12 + beacon mount and More HeadRoom mods
    [Endstop.step, Left Lower.step, Left Upper.step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]
